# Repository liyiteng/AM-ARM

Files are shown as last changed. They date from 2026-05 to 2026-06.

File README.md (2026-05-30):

# AM-ARM200

 

AM-ARM200 is a low-cost, open-source 6+1 DoF robotic arm with a 1 kg payload, fully 3D-printable and built for embodied AI research.

Built on the open-source philosophy of SO-ARM100, it brings the platform into a new capability class while remaining easy to reproduce and affordable.

~$240 follower / ~$140 leader / ~$380 full teleoperation kit.

> Looking for the complete AlohaMini robot? See the [AlohaMini repository](https://github.com/liyiteng/alohamini).

## Updates

- **[2026-05-29]** URDF files coming soon

### What Makes It Different

- **6+1 DoF, 1 kg payload, 52 cm reach** — a capability class rarely seen at this price point
- **LeRobot & AlohaMini compatible** — works out of the box with the most popular open-source robot learning stack
- **Fully 3D-printable** — print and assemble at home in ~60 minutes
- **Open source** — CAD, firmware, and software included
- **Low cost** — ~$240 follower / ~$140 leader / ~$380 full teleoperation kit

## Gallery

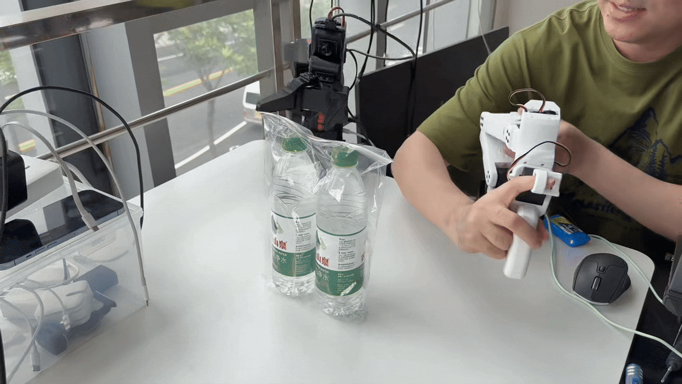
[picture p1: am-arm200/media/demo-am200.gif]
AM-ARM200


## Bill of Materials

### AM-ARM200 Follower

| Item | Qty | Unit (USD) | Subtotal (USD) |
|---|---:|---:|---:|
| Feetech STS3215 servo (12V, 1/345) | 4 | $16 | $64 |
| Feetech STS3095 servo (12V, 1/399) | 3 | $50 | $150 |
| Waveshare bus servo controller | 1 | $5 | $5 |
| 12V 4A power supply | 1 | $14 | $14 |
| Bearings, fasteners, cables | — | — | ~$10 |
| 3D-printed parts | — | — | self-print |
| **Total** | | | **~$243** |

### AM-ARM200 Leader

| Item | Qty | Unit (USD) | Subtotal (USD) |
|---|---:|---:|---:|
| Feetech STS3215 servo (5V, 1/147) | 7 | $16 | $112 |
| Waveshare bus servo controller | 1 | $5 | $5 |
| 5V 4A power supply | 1 | $10 | $10 |
| Bearings, fasteners, cables | — | — | ~$10 |
| 3D-printed parts | — | — | self-print |
| **Total** | | | **~$137** |

## Getting Started

### 1. Buy components

Order servos, controller, power supply, and small parts. See [BOM](am-arm200/bom.md).

### 2. Print parts

~20 hours on a standard FDM printer. See [3D printing guide](am-arm200/3d-print.md).

### 3. Assemble

Build a leader + follower pair in ~60 minutes. See [assembly guide](am-arm200/hardware_assembly.md).

### 4. Software setup

All software steps are in the **[lerobot_alohamini](https://github.com/liyiteng/lerobot_alohamini)** shared software repository. Follow the steps below in order — each links directly to the relevant section.

| Step | What | Where |
|---|---|---|
| 1 | Install environment | [install.md](https://github.com/liyiteng/lerobot_alohamini/blob/main/docs/alohamini/install.md) |
| 2 | Find arm ports | [§1 Port Configuration](https://github.com/liyiteng/lerobot_alohamini/blob/main/docs/alohamini/am-arm200.md#1-port-configuration) |
| 3 | Calibrate arms & teleoperate | [§3 Calibration](https://github.com/liyiteng/lerobot_alohamini/blob/main/docs/alohamini/am-arm200.md#3-calibration) |
| 4 | Record a dataset | [§5 Dataset Recording](https://github.com/liyiteng/lerobot_alohamini/blob/main/docs/alohamini/am-arm200.md#5-dataset-recording) |
| 5 | Train a policy | [§8 Training](https://github.com/liyiteng/lerobot_alohamini/blob/main/docs/alohamini/am-arm200.md#8-training) |
| 6 | Evaluate the policy | [§9 Evaluation](https://github.com/liyiteng/lerobot_alohamini/blob/main/docs/alohamini/am-arm200.md#9-evaluation) |

<details>
<summary><strong>Advanced: patch upstream LeRobot instead of using lerobot_alohamini</strong></summary>

If you already have a working LeRobot environment and prefer to stay on the upstream repo, you can add STS3095 support manually with two changes.

**Step 1 — Register STS3095 in the motor table**

In `lerobot/src/lerobot/motors/feetech/tables.py`, add `"sts3095"` to each of the five model dictionaries. STS3095 is STS-series (same protocol as STS3215), so the values mirror that motor:

```python
MODEL_CONTROL_TABLE = {
    ...
    "sts3095": STS_SMS_SERIES_CONTROL_TABLE,   # add this
}

MODEL_RESOLUTION = {
    ...
    "sts3095": 4096,                            # add this
}

MODEL_BAUDRATE_TABLE = {
    ...
    "sts3095": STS_SMS_SERIES_BAUDRATE_TABLE,   # add this
}

MODEL_ENCODING_TABLE = {
    ...
    "sts3095": STS_SMS_SERIES_ENCODINGS_TABLE,  # add this
}

MODEL_PROTOCOL = {
    ...
    "sts3095": 0,                               # add this (STS series = protocol 0)
}
```

**Step 2 — Update the follower robot definition**

In `lerobot/src/lerobot/robots/so_follower/so_follower.py`, replace the motor list with the AM-ARM200's 7-motor layout (adds `wrist_yaw` and swaps the three high-torque joints to `sts3095`):

```python
motors=(
    ("shoulder_pan",  1, "sts3095", None),
    ("shoulder_lift", 2, "sts3095", None),
    ("elbow_flex",    3, "sts3095", None),
    ("wrist_flex",    4, "sts3215", None),
    ("wrist_yaw",     5, "sts3215", None),
    ("wrist_roll",    6, "sts3215", None),
    ("gripper",       7, "sts3215", MotorNormMode.RANGE_0_100),
),
```

After these two edits, the rest of the LeRobot workflow (calibration, teleop, recording, training) is identical to the standard SO-ARM100 setup.

> Note: `lerobot_alohamini` already includes both changes — use the upstream path only if you have a specific reason to avoid the fork.

</details>

## Product Line

| Model | Build | Servos | Target Users | Buy (CN) |
|---|---|---|---|---|
| **AM-ARM200** | Fully 3D-printed | STS3215 | Makers, students, research labs | [Taobao](https://item.taobao.com/item.htm?abbucket=4&id=1015799132286) |
| **AM-ARM200 Pro** | Fully 3D-printed | Industrial STS3250 | Research institutions, university labs needing higher durability | [Taobao](https://item.taobao.com/item.htm?abbucket=4&id=1015799132286) |

> Same software stack across both versions. AM-ARM200 remains fully open-source and self-buildable. See [am-arm200-pro/](am-arm200-pro/) for Pro details.

## Team & Contact

AM-ARM200 is created by **Li Yiteng** and **Wu Zhiyong**.

- Email: liyiteng+github@gmail.com
- WeChat: liyiteng
- Videos & tutorials: Bilibili / YouTube

## Acknowledgements

- [LeRobot](https://github.com/huggingface/lerobot) — the software stack this arm targets
- [ALOHA](https://tonyzhaozh.github.io/aloha/) — the bimanual teleoperation paradigm
- [SO-ARM100](https://github.com/TheRobotStudio/SO-ARM100) — pioneered the low-cost open arm design pattern

---

If this project is useful to you, a ⭐ helps others find it.

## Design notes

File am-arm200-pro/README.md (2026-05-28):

# AM-ARM200 Pro

> **Coming Soon**

AM-ARM200 Pro is currently in development.

Key upgrade: servos upgraded from STS3215 to industrial-grade STS3250 for higher torque and reliability. Designed for research institutions and university laboratories that demand greater durability and performance. More details to follow.

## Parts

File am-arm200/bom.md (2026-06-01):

# AM-ARM200 Bill of Materials

AM-ARM200 builds on the SO-ARM100 design philosophy with increased payload capacity, longer reach, and an additional degree of freedom.

Existing SO100/SO101 users can smoothly upgrade to AM-ARM200 by simply adding the missing parts.

## Follower Arm

| Item | Model / Notes | Qty | Unit Cost (US/EU) | Buy (US) | Unit Cost (CN) | Buy (CN) |
|---|---|----:|---|---|---|---|
| Servo motor | Feetech STS3215 (12V 1/345) | 4 | $15.97 | [Alibaba](https://www.alibaba.com/product-detail/Lerobot-360-Degree-Smart-Servo-for_1601563310522.html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) | ¥110 | [Taobao](https://e.tb.cn/h.64H9u3maGWzIp5Q?tk=T5liexkG6Yz) |
| Servo motor | Feetech STS3095 (12V 1/345) | 3 | $50.37 | [Alibaba](https://www.alibaba.com/product-detail/FEETECH-STS3095-12V-95KG-servo-AI_1601045980686.html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) | ¥345 | [Taobao](https://item.taobao.com/item.htm?id=766143777848&skuId=6096958421597) |
| Hex socket screw | M3×10 | 74 | — | — | ¥6 | [Taobao](https://e.tb.cn/h.R0nMFj8y9riNyJl?tk=HNii5rHz4NJ) |
| Heat-set insert | M3×5×4 | 4 | — | Amazon | ¥5 | [Taobao](https://item.taobao.com/item.htm?id=809241671998) |
| Servo extension cable | SCS 3-pin, 26 cm | 6 | $0.43 | [AliExpress](https://www.aliexpress.com/item/1005008074862037.html) | ¥3 | [Taobao](https://item.taobao.com/item.htm?id=616460581906) |
| Power supply | DC 12V 4A 48W AC Adapter | 1 | $13.76 | [Amazon](https://www.amazon.com/Snsnlent-Adapter-5-5x2-1mm-Monitor-Voltage/dp/B085ZXPD34/) | ¥24 | [Taobao](https://item.taobao.com/item.htm?id=544862301228) |
| USB Type-C cable | — | 1 | $7.00 | [Amazon](https://www.amazon.com/Charging-etguuds-Charger-Braided-Compatible/dp/B0B8NWLLW2/) | ¥20 | [Tmall](https://detail.tmall.com/item.htm?id=754024805047) |
| Waveshare Bus Servo Controller | — | 1 | $5.00 | [Waveshare](https://www.waveshare.com/bus-servo-adapter-a.htm) | ¥27 | [Tmall](https://detail.tmall.com/item.htm?id=738817173460) |
| 3D-printed parts | PLA/PETG/ABS — [STL](stl/) / [STP](stp/) | 1 | — | — | — | — |

**Follower Total: $243.33**

---

## Leader Arm

| Item | Model / Notes | Qty | Unit Cost (US) | Buy (US) | Unit Cost (CN) | Buy (CN) |
|---|---|----:|---|---|---|---|
| Servo motor | Feetech STS3215 (5V 1/147) | 7 | $15.97 | [Alibaba](https://www.alibaba.com/product-detail/Lerobot-360-Degree-Smart-Servo-for_1601563310522.html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) | ¥110 | [Taobao](https://e.tb.cn/h.64H9u3maGWzIp5Q?tk=T5liexkG6Yz) |
| Heat-set insert | M3×5×4, total 36 pcs (Servo Mount×24, Side Panel×12) | 4 | — | Amazon | ¥5 | [Taobao](https://item.taobao.com/item.htm?id=809241671998) |
| Power supply | DC 5V AC Adapter | 1 | $12.99 | [Amazon](https://www.amazon.com/Facmogu-Switching-Transformer-Compatible-5-5x2-1mm/dp/B087LY41PV/) | — | — |
| USB Type-C cable | — | 1 | $7.19 | [Amazon](https://www.amazon.com/Charging-etguuds-Charger-Braided-Compatible/dp/B0B8NWLLW2/) | ¥20 | [Tmall](https://detail.tmall.com/item.htm?id=754024805047) |
| Waveshare Bus Servo Controller | — | 1 | $12.47 | [Amazon](https://www.amazon.com/Waveshare-Integrates-Control-Circuit-Supports/dp/B0CTMM4LWK/) | ¥27 | [Tmall](https://detail.tmall.com/item.htm?id=738817173460) |
| 3D-printed parts | PLA/PETG/ABS — [STL](stl/) / [STP](stp/) | 1 | — | — | — | — |

**Leader Total: $144.44**

---

## Optional

| Item | Model / Notes | Qty | Unit Cost (US) | Buy (US) | Unit Cost (CN) | Buy (CN) |
|---|---|----:|---|---|---|---|
| USB camera | 720p, 36×36 mm form factor | 1 | — | Amazon | ¥125 | [Taobao](https://item.taobao.com/item.htm?id=666278411821) |
| M2×12 Phillips screw | For camera mounts | 2 | — | — | — | — |
| Bearing | 12×18×4 mm (ID × OD × W) | 2 | $0.30 | [Amazon](https://www.amazon.com/XIKE-6701-2RS-Bearings-12x18x4mm-Pre-Lubricated/dp/B09D2RQ4Y1) | ¥6 | [Tmall](https://detail.tmall.com/item.htm?id=824704356695) |

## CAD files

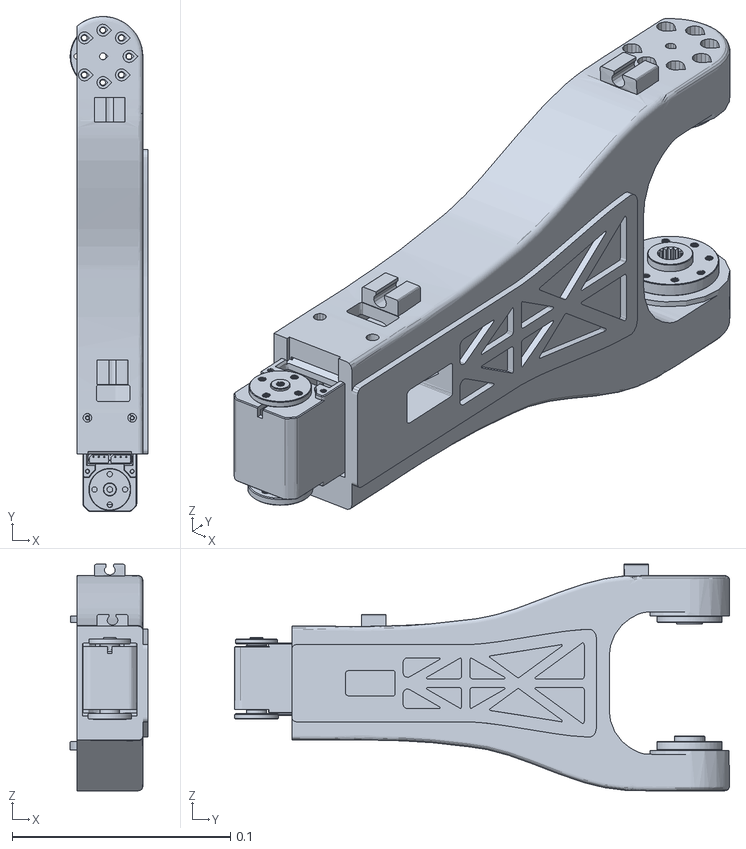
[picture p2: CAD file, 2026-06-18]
am-arm200-pro/urdf/am-arm200pro-meshes/left_Lower_Arm.STL
0.0356 x 0.227 x 0.104

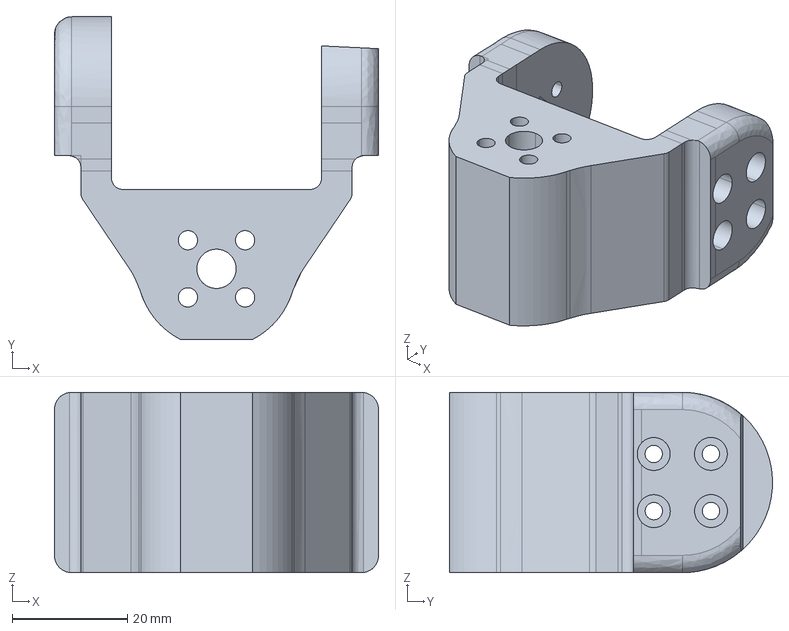
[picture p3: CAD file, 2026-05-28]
am-arm200/stp/follower/OB_F_J5_Elbow_Wrist_Bracket.stp
56.1 x 55.9 x 31.2 mm

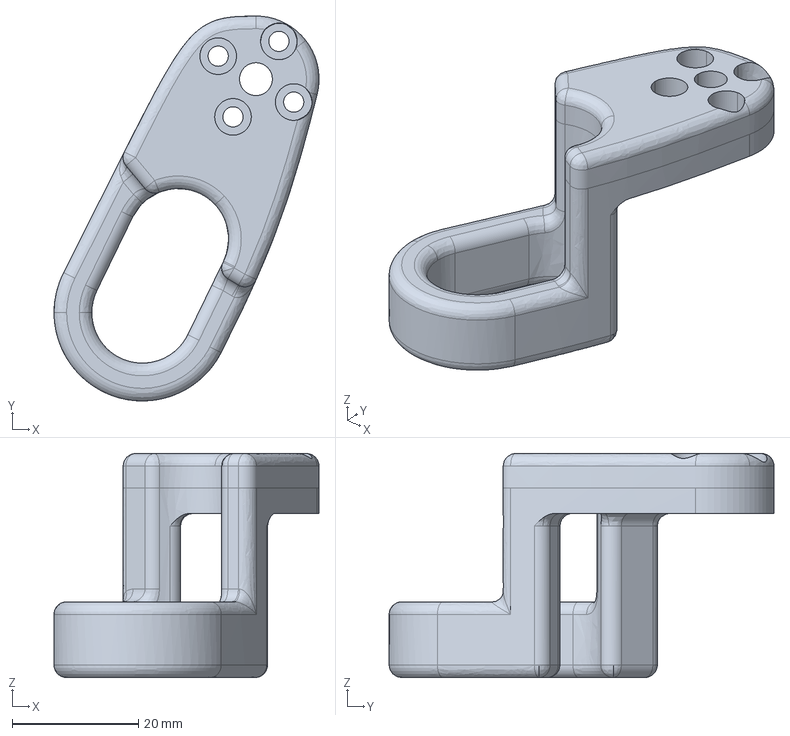
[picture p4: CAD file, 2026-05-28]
am-arm200/stp/leader/O_L_J7_Trigger.stp
42.0 x 61.0 x 35.5 mm

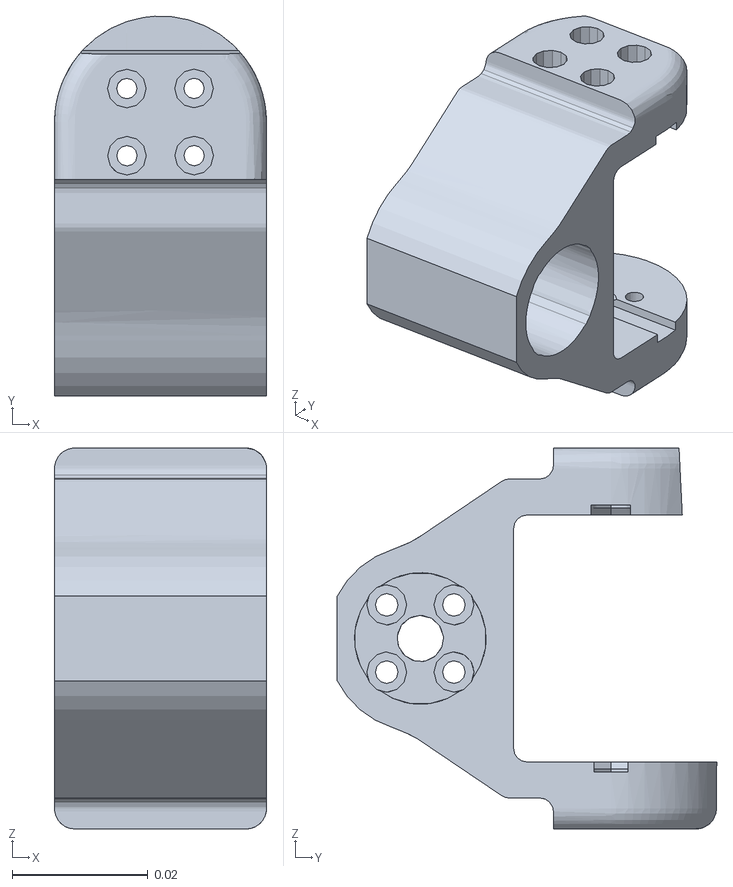
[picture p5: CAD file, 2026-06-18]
am-arm200/urdf/am-arm200-meshes/left_Wrist_Pitch_Roll.STL
0.0312 x 0.0559 x 0.0561

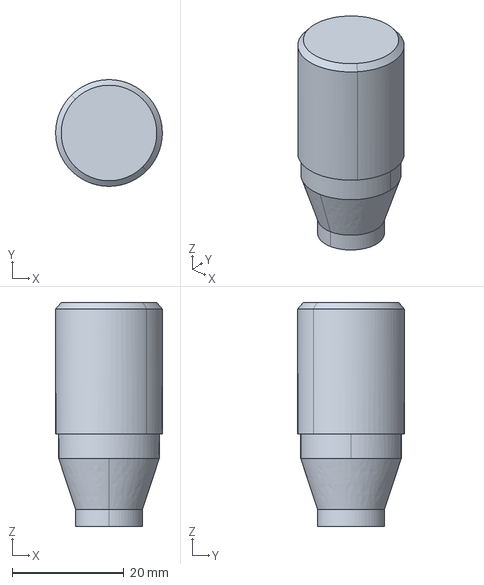
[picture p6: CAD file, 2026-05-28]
am-arm200/stp/follower/OB_F_J5_Pin_Bearing.stp
19.1 x 19.1 x 40.1 mm

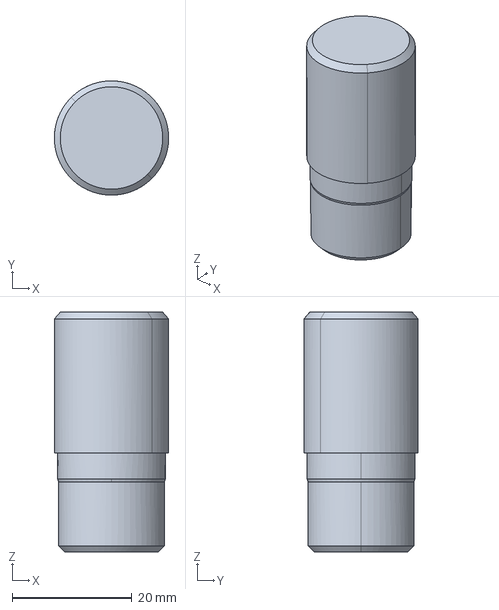
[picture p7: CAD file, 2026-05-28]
am-arm200/stp/leader/O_L_J5_Pin_No_Bearing.stp
19.1 x 19.1 x 40.1 mm

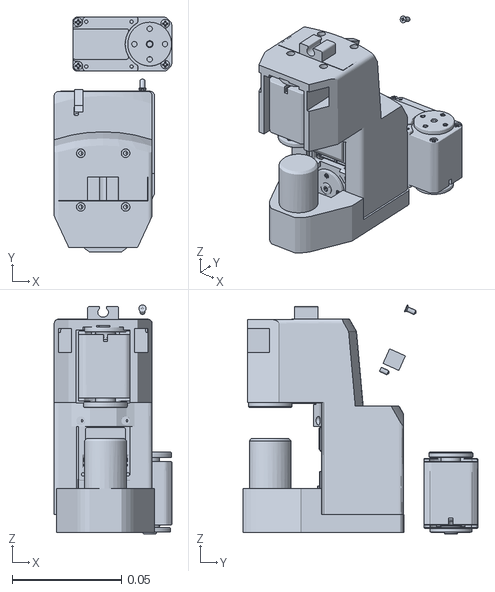
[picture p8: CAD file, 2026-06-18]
am-arm200/urdf/am-arm200-meshes/left_wrist_yaw.STL
0.0538 x 0.107 x 0.105

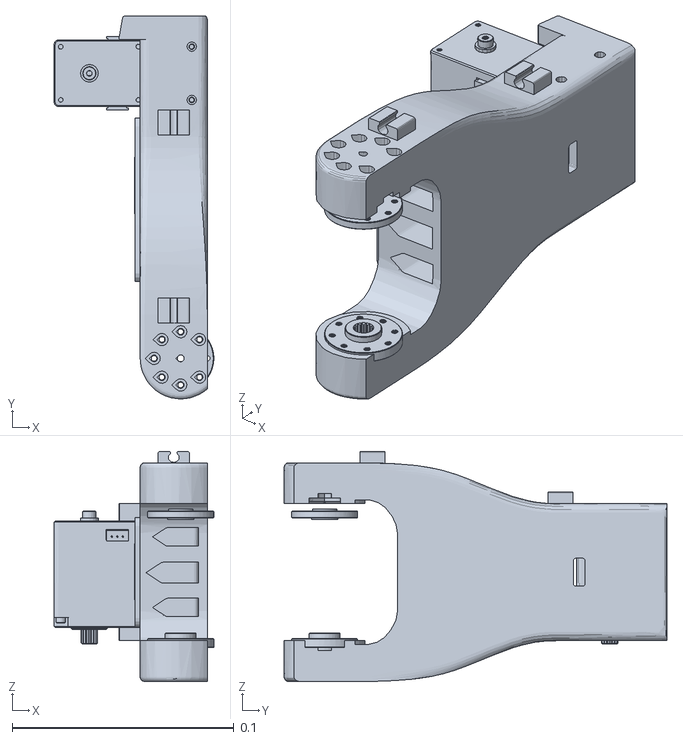
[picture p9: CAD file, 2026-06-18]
am-arm200-pro/urdf/am-arm200pro-meshes/left_Upper_Arm.STL
0.072 x 0.173 x 0.104

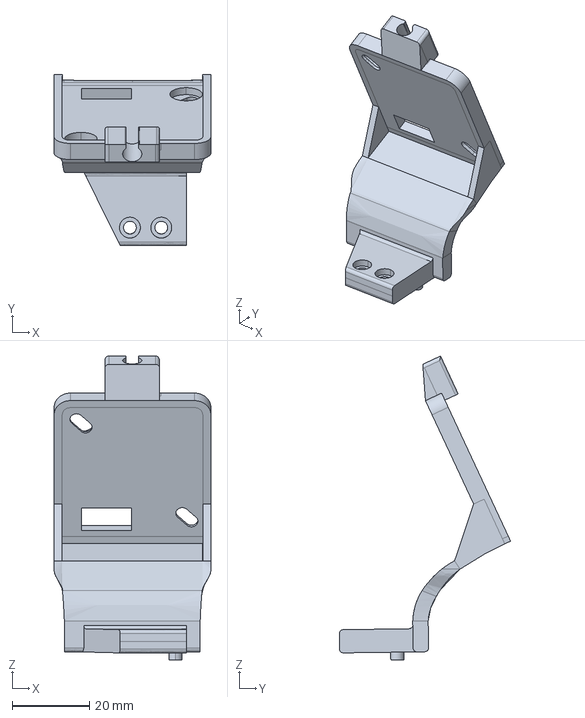
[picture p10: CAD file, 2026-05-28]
am-arm200/stp/follower/OB_F_Camera.stp
40.5 x 44.2 x 78.5 mm

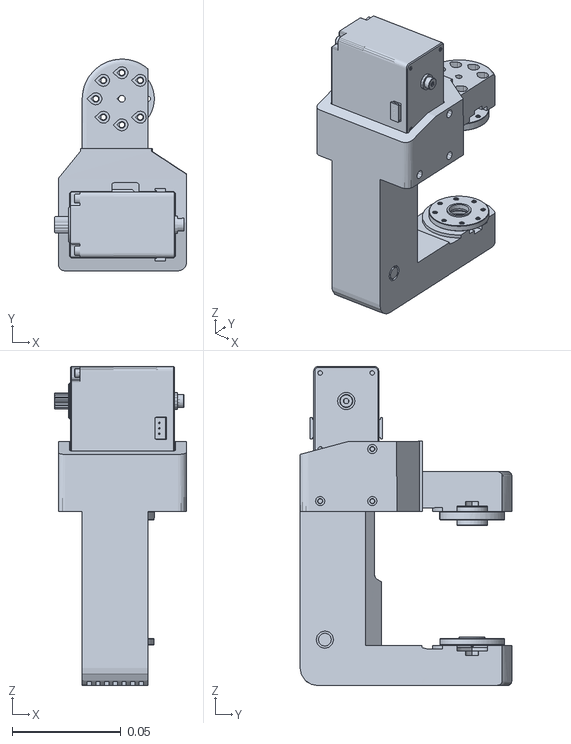
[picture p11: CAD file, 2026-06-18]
am-arm200/urdf/am-arm200-meshes/left_Rotation_Pitch.STL
0.0609 x 0.0975 x 0.147

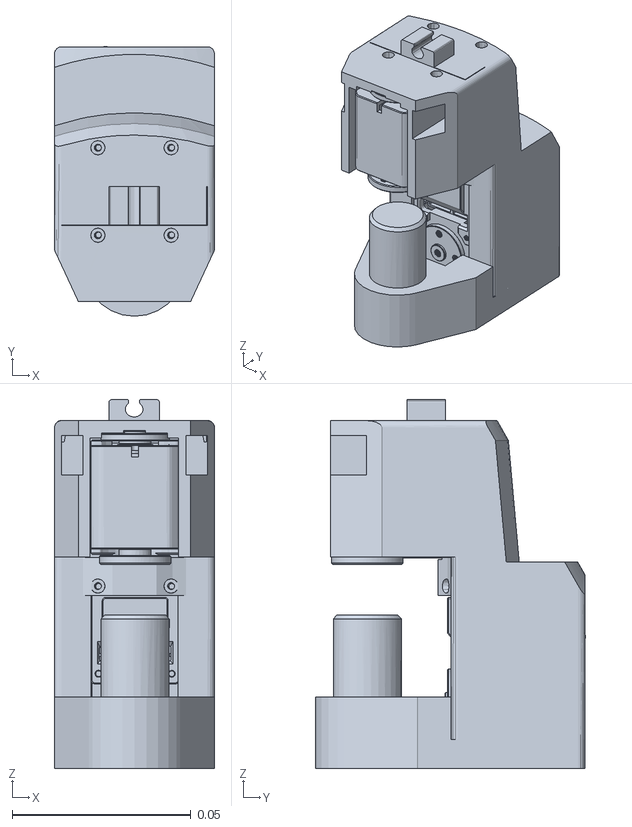
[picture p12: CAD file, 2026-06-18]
am-arm200-pro/urdf/am-arm200pro-meshes/left_wrist_yaw.STL
0.0448 x 0.0755 x 0.103

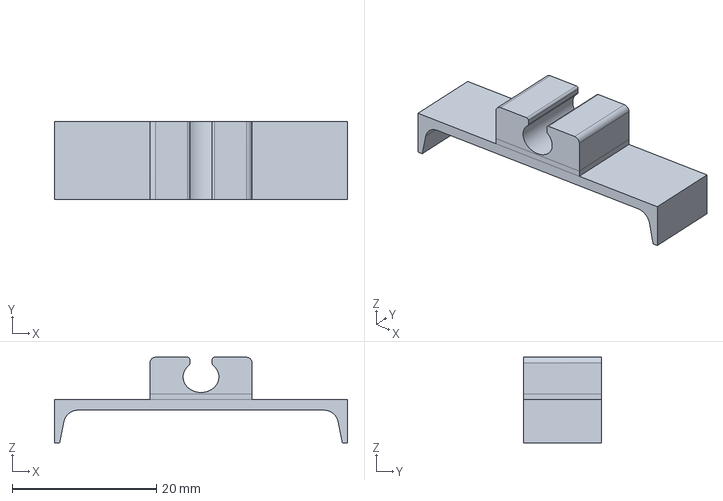
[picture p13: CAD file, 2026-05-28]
am-arm200/stp/follower/OB_F_J56_Top.stp
40.6 x 10.8 x 11.9 mm

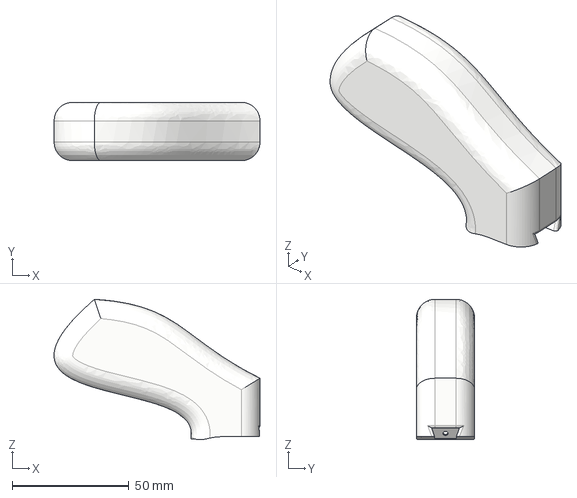
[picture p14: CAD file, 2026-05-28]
am-arm200/stp/leader/O_L_J7_Handle.stp
88.1 x 25.0 x 60.1 mm

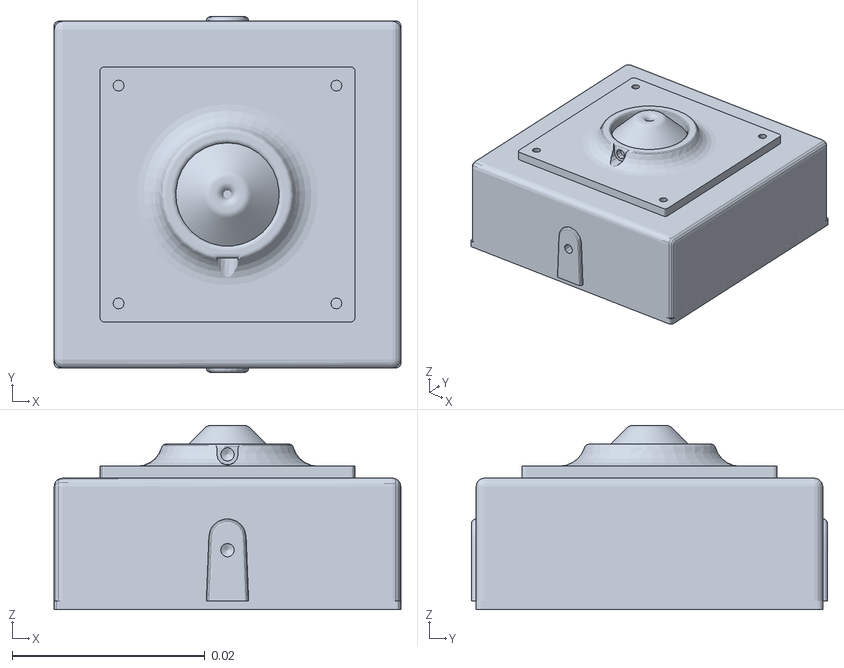
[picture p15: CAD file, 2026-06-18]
am-arm200/urdf/am-arm200-meshes/left_camera.STL
0.036 x 0.037 x 0.0191

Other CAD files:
am-arm200-pro/urdf/am-arm200pro-meshes/left_Wrist_Pitch_Roll.STL
am-arm200-pro/urdf/am-arm200pro-meshes/left_Rotation_Pitch.STL
am-arm200/stp/follower/OB_F_J3_Shoulder.stp
am-arm200-pro/urdf/am-arm200pro-meshes/left_Base.STL
am-arm200-pro/urdf/am-arm200pro-meshes/left_Fixed_Jaw.STL
am-arm200-pro/urdf/am-arm200pro-meshes/left_Moving_Jaw.STL
am-arm200-pro/urdf/am-arm200pro-meshes/left_camera.STL
am-arm200/stl/follower/OB_F_Camera.stl
am-arm200/stl/follower/OB_F_J3_Shoulder.stl
am-arm200/stl/follower/OB_F_J4_Elbow.stl
am-arm200/stl/follower/OB_F_J56_Bottom.stl
am-arm200/stl/follower/OB_F_J56_Top.stl
am-arm200/stl/follower/OB_F_J56_Wrist_Housing.stl
am-arm200/stl/follower/OB_F_J5_Elbow_Wrist_Bracket.stl
am-arm200/stl/follower/OB_F_J5_Pin_Bearing.stl
am-arm200/stl/follower/OB_F_J5_Pin_No_Bearing.stl
am-arm200/stl/follower/OB_F_J7_Gripper.stl
am-arm200/stl/follower/OB_F_J7_Jaw.stl
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

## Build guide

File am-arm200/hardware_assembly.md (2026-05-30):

# Hardware Assembly Guide

This guide covers the AM-ARM200 follower arm assembly. Install all screws loosely at first, then tighten them after the parts are aligned.

## Servo ID Setup

Before assembly, assign the correct ID to each servo. We recommend using the [`lerobot_alohamini`](https://github.com/liyiteng/lerobot_alohamini)debug command.

### Option 1: lerobot_alohamini (Recommended)

Set the servo ID with the `lerobot_alohamini` [debug command](https://github.com/liyiteng/lerobot_alohamini/blob/main/examples/debug):
```bash
python examples/debug/motors.py configure_motor_id \
  --id 1 \
  --set_id 2 \
  --port /dev/ttyACM0
```

### Option 2: FD Debug Tool

You can also use the Feetech [FD Debug Tool](https://www.feetechrc.com/Data/feetechrc/upload/file/20240622/FD1.9.8.3.zip), for example FD Debug Tool v1.9.8.3.

1. Download and install the FD Debug Tool.
2. Connect one servo to your computer through the Waveshare Bus Servo Controller.
3. Open the FD Debug Tool.
4. Select the correct COM port and baud rate. The typical baud rate is `1000000`.
5. Click `Scan Servo` to detect the connected servo and read its current ID.
6. Enter the target ID in the ID field.
7. Click `Write` or `Save` to update the servo ID.
8. Disconnect the servo and repeat the process for the remaining servos.

## Leader Arm (5V)

### 1. Configure the servos

Connect the 5V power supply to the servo controller, connect the controller to your PC with a USB-C cable, and connect one servo to the controller.

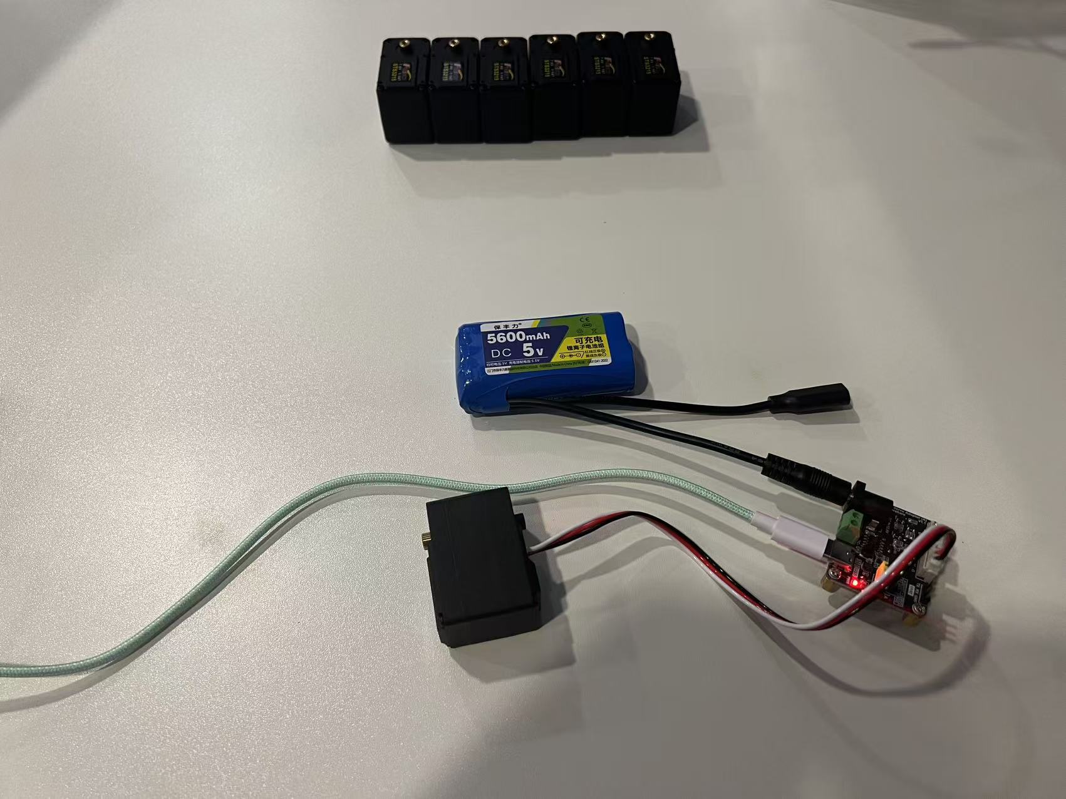
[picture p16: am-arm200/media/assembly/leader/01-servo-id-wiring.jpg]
Leader servo ID wiring


Set the servo IDs one by one.

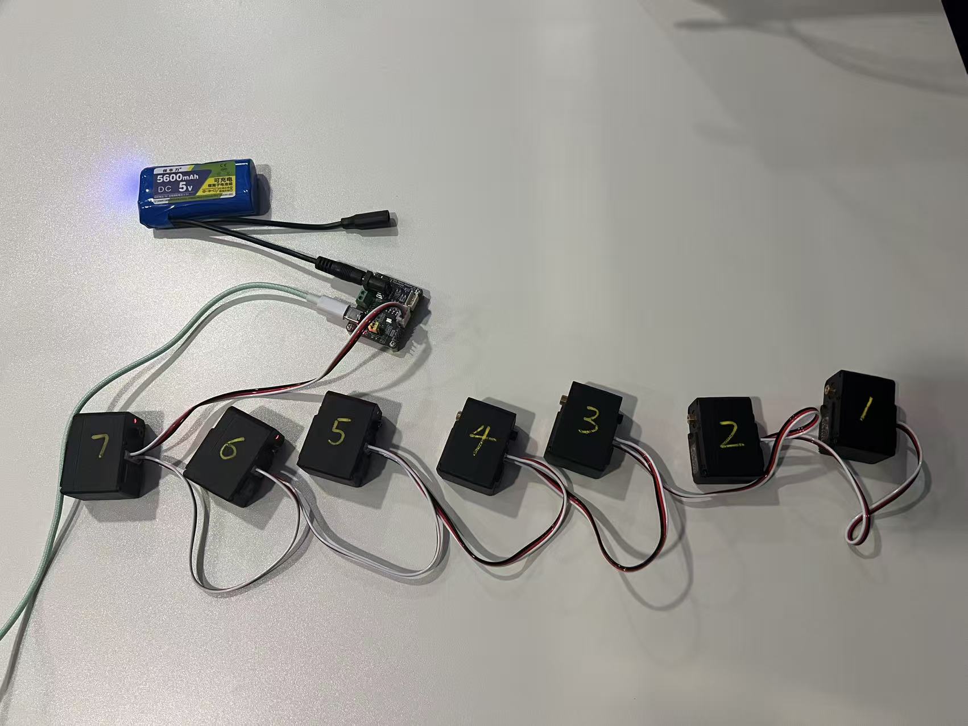
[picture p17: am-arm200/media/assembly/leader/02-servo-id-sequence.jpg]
Leader servo ID sequence


Use the following layout as the reference for servo IDs 1-7 on the leader arm.

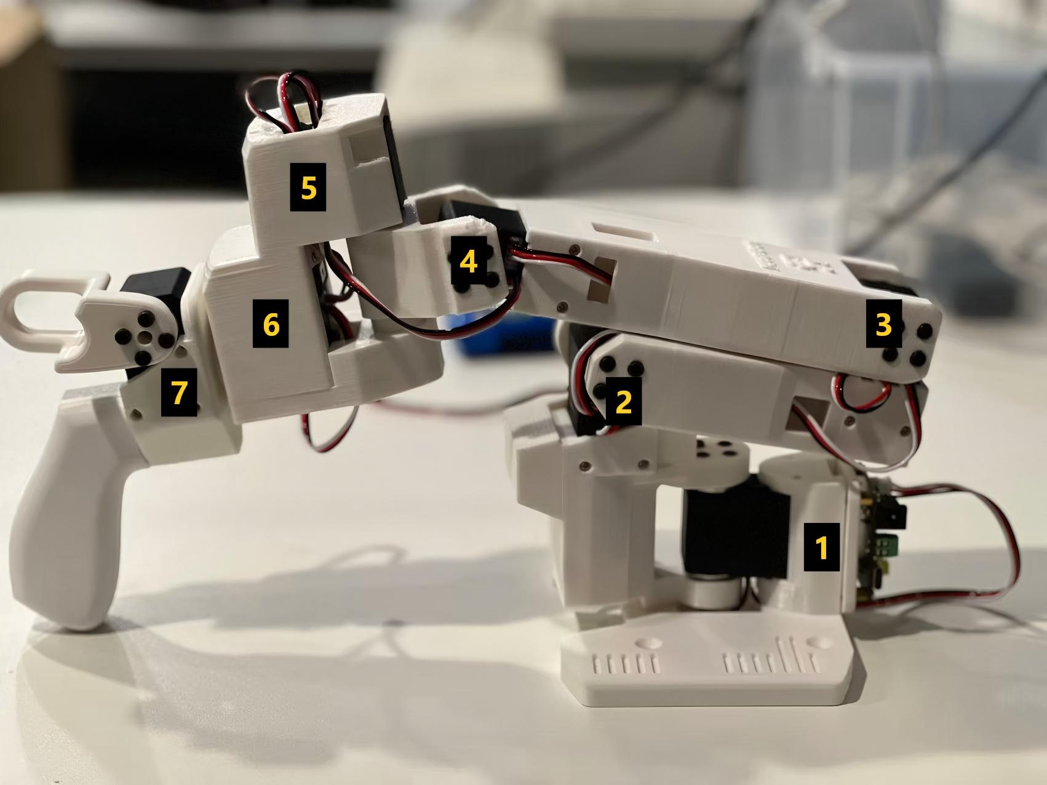
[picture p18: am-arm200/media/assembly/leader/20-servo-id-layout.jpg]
Leader servo ID layout


The 5V 1/147 servos are configured for multi-turn mode at the factory. Using the same `lerobot_alohamini` [debug command](https://github.com/liyiteng/lerobot_alohamini/blob/main/examples/debug) setup, set the servo phase to `12` to reset them to single-turn mode:

```bash
python examples/debug/motors.py configure_motor_phase \
  --set_phase 12 \
  --port /dev/ttyACM0
```

After configuration, use `get_motors_states` to check the servo status:

```bash
python examples/debug/motors.py get_motors_states \
  --port /dev/ttyACM0
```

### 2. Assemble the base and shoulder

After the servo IDs and phase are configured, start the mechanical assembly.

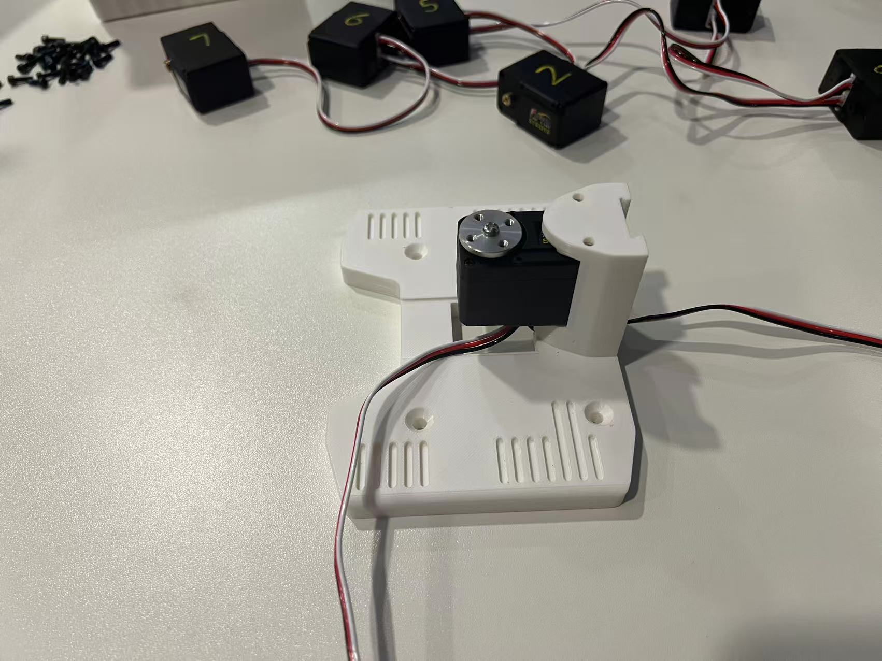
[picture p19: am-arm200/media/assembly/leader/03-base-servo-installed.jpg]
Leader base servo installed


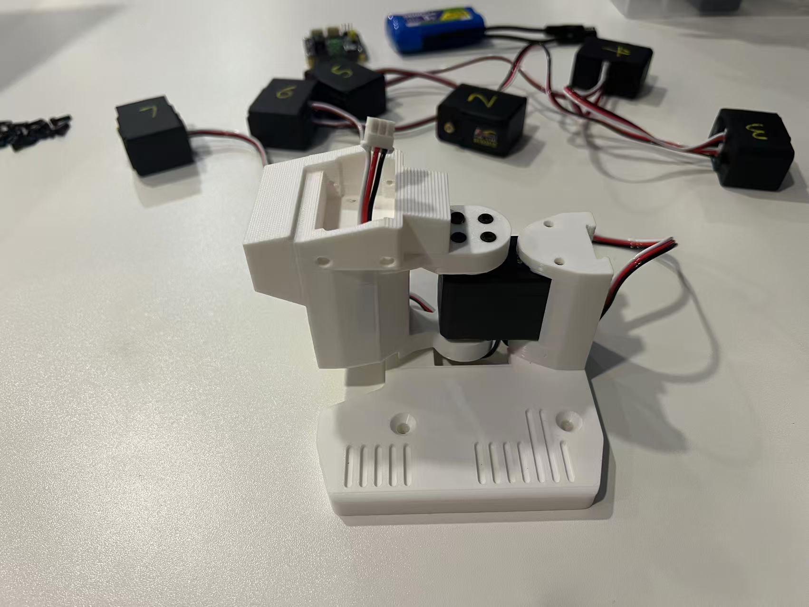
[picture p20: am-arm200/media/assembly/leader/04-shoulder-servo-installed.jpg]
Leader shoulder servo installed


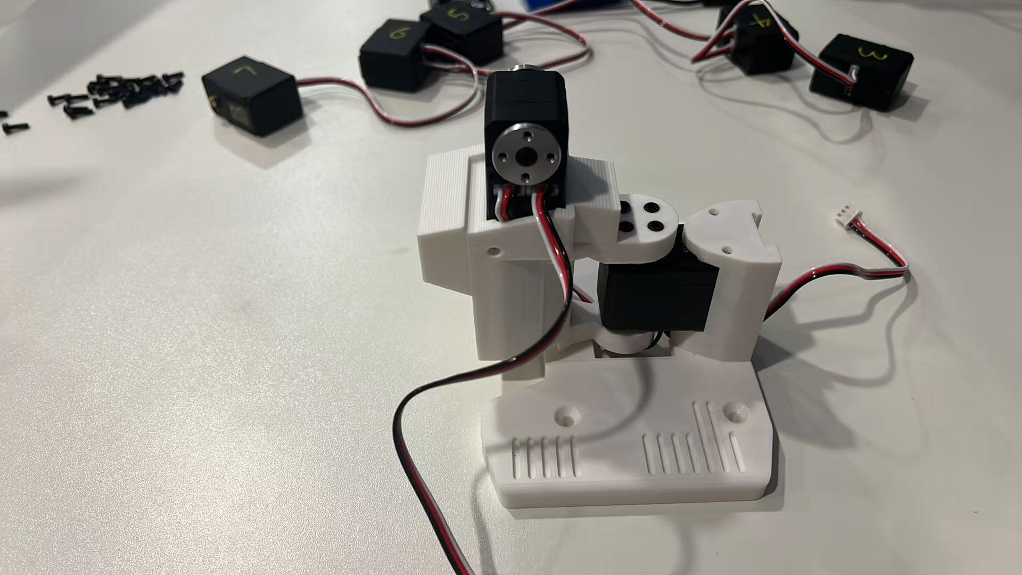
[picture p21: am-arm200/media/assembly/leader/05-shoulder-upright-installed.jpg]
Leader shoulder upright installed


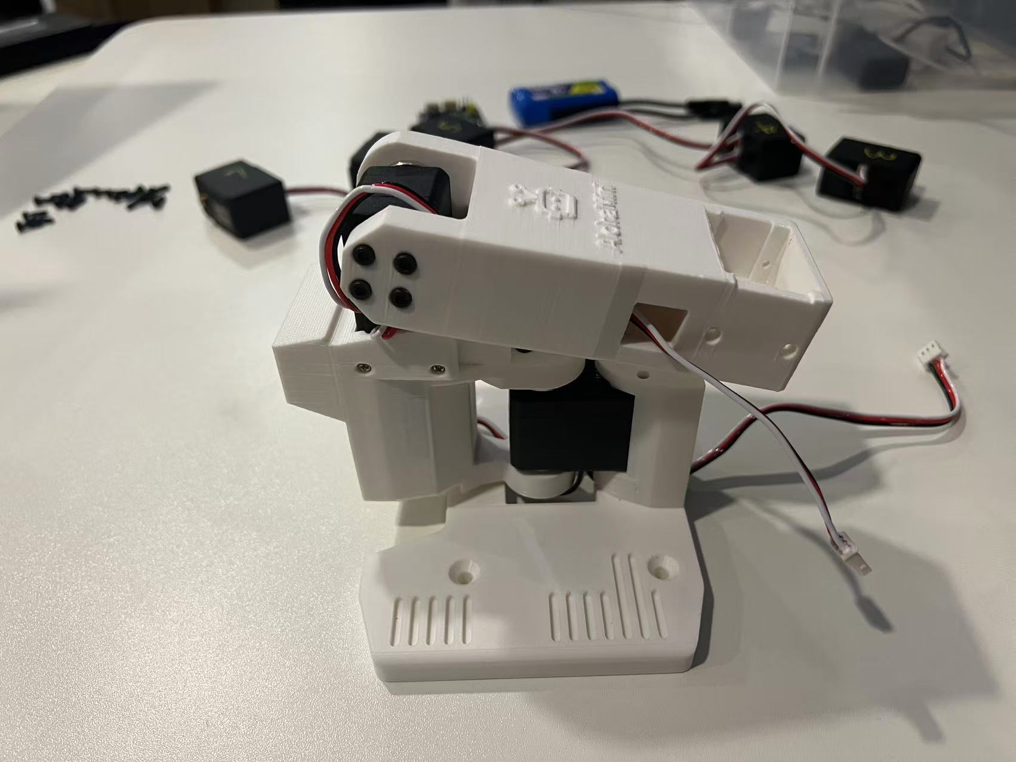
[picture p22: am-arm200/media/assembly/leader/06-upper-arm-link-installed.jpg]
Leader upper arm link installed


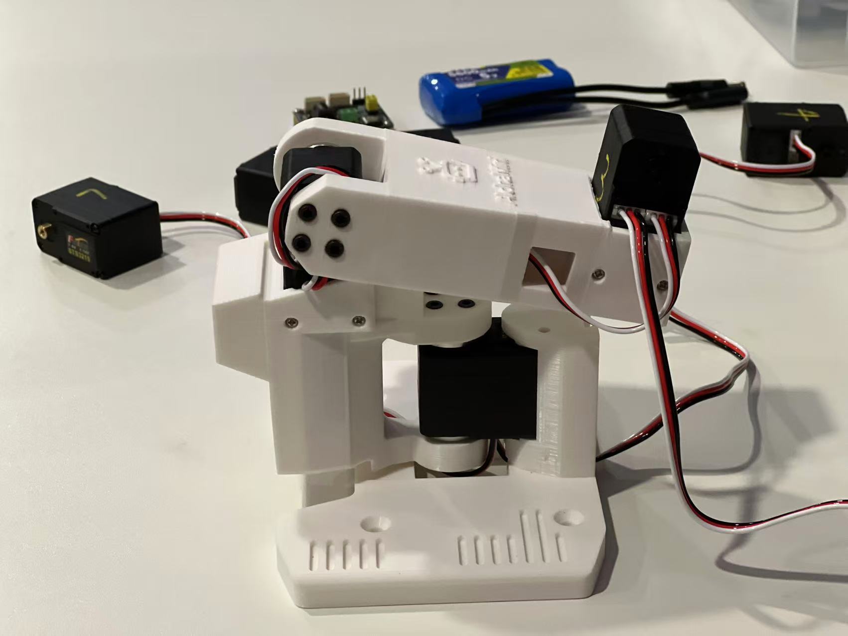
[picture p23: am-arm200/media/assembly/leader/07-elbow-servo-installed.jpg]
Leader elbow servo installed


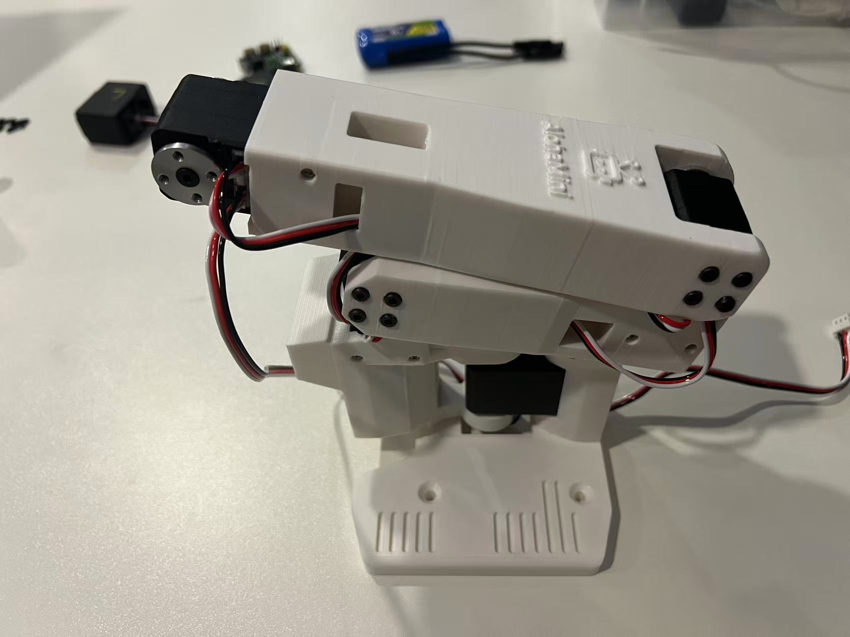
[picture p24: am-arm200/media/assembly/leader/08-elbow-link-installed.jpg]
Leader elbow link installed


### 3. Install heat-set inserts

Install the heat-set inserts into the J56 printed part.

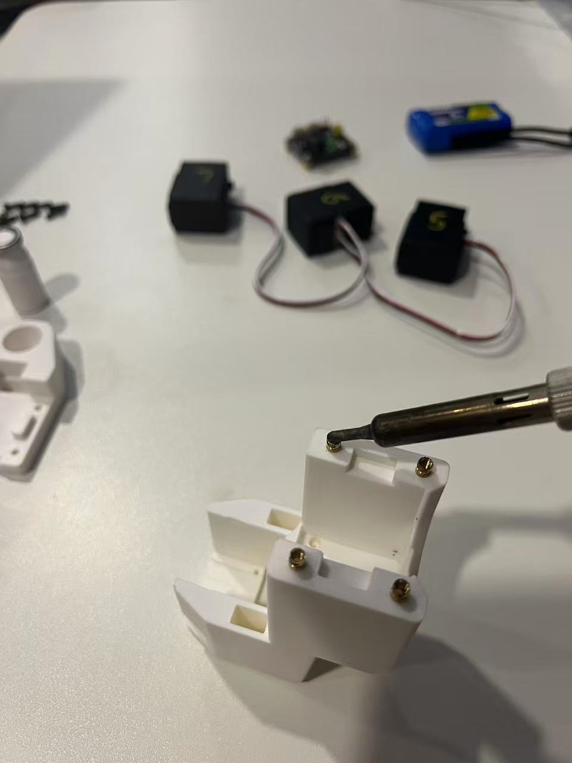
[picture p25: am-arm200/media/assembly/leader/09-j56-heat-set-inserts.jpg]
J56 heat-set inserts


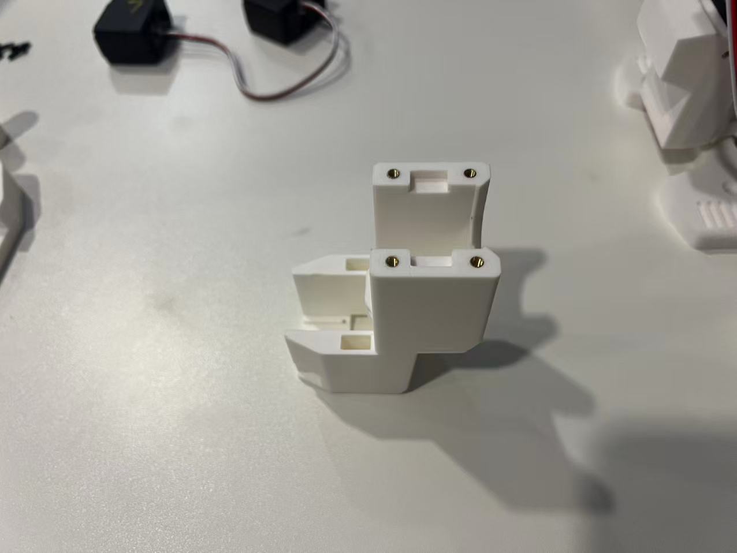
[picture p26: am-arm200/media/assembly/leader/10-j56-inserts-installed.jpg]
J56 heat-set inserts installed


### 4. Assemble the wrist

Install the wrist servo, bearing, and wrist cover.

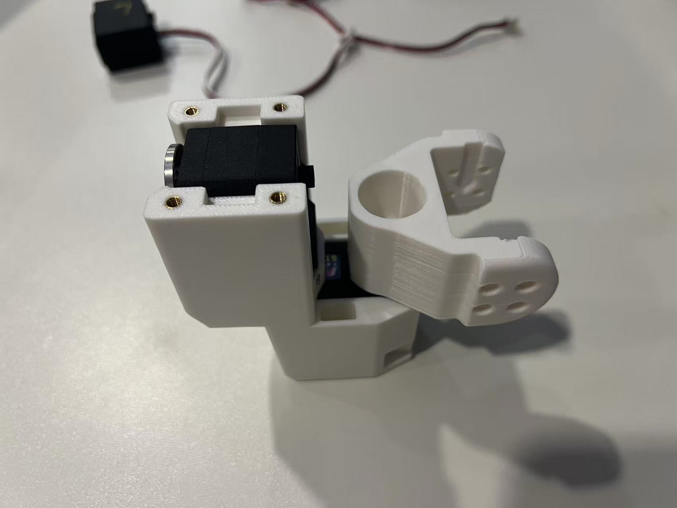
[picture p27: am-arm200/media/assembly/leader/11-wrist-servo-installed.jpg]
Leader wrist servo installed


Install the pin and bearing. Alternatively, use the no-bearing version: `O_L_J5_Pin_No_Bearing.stl`.
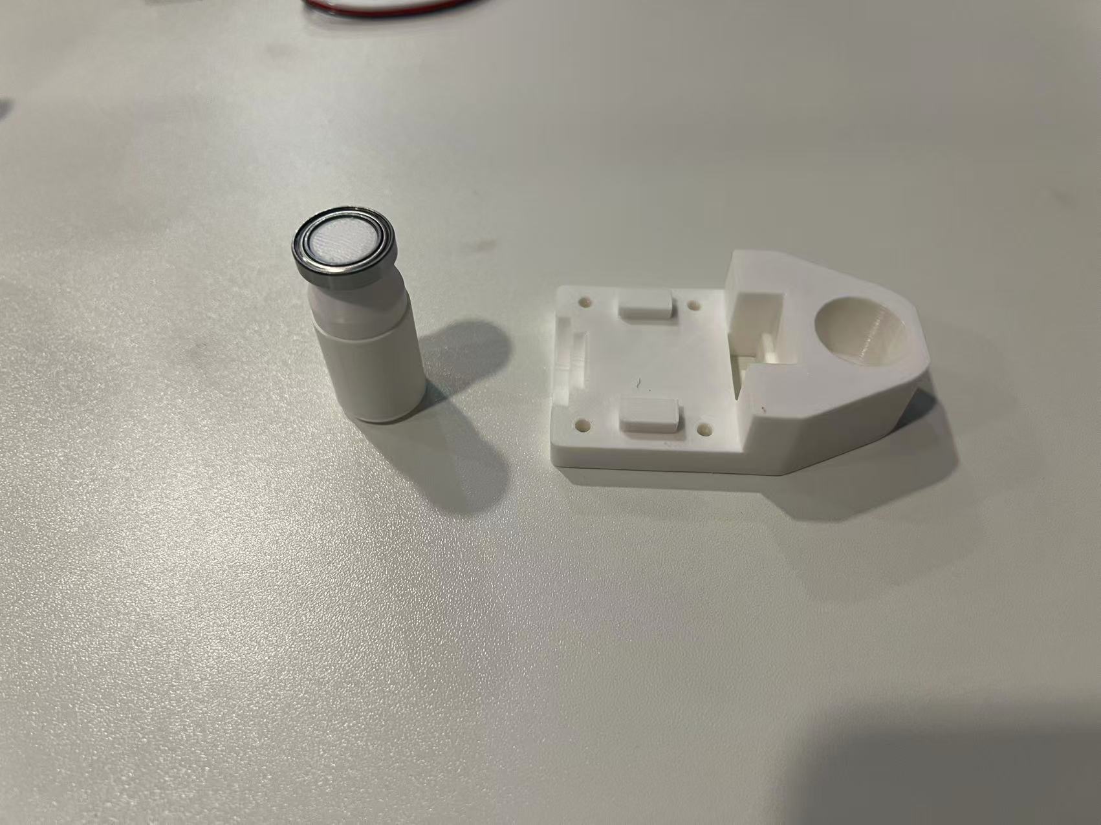
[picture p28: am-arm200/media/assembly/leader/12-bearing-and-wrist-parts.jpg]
Leader bearing and wrist parts


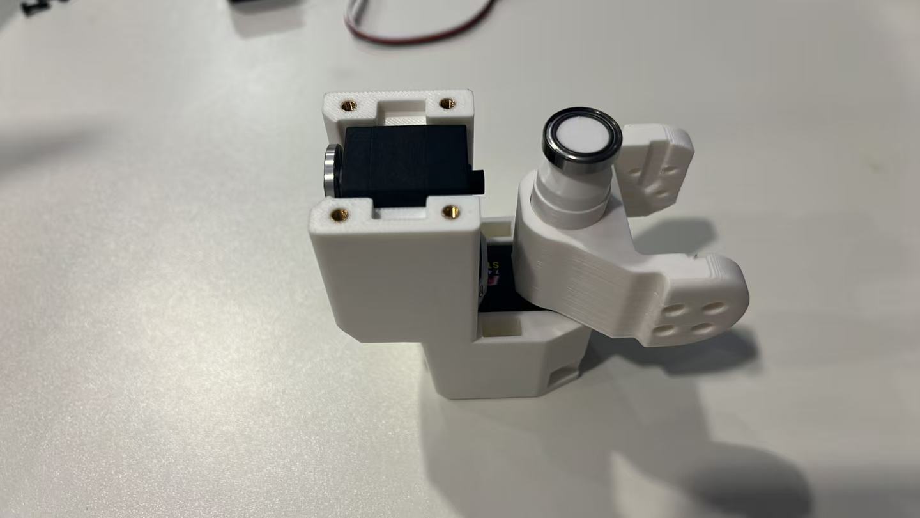
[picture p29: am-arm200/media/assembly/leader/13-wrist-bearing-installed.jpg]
Leader wrist bearing installed


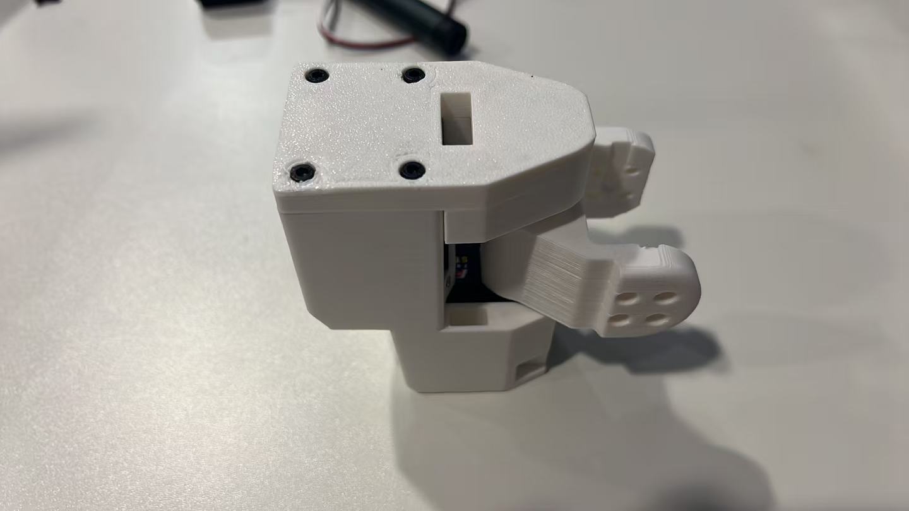
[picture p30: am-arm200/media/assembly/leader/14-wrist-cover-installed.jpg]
Leader wrist cover installed


### 5. Assemble the gripper

Install the gripper linkage and gripper servo.

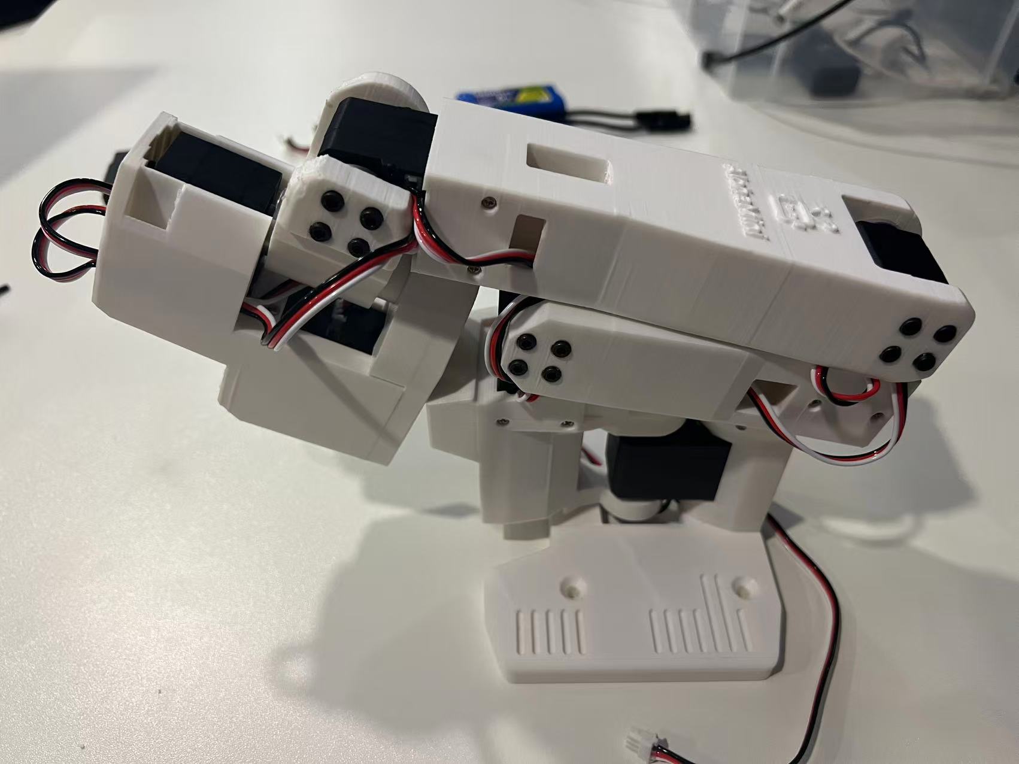
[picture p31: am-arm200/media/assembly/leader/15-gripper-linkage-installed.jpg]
Leader gripper linkage installed


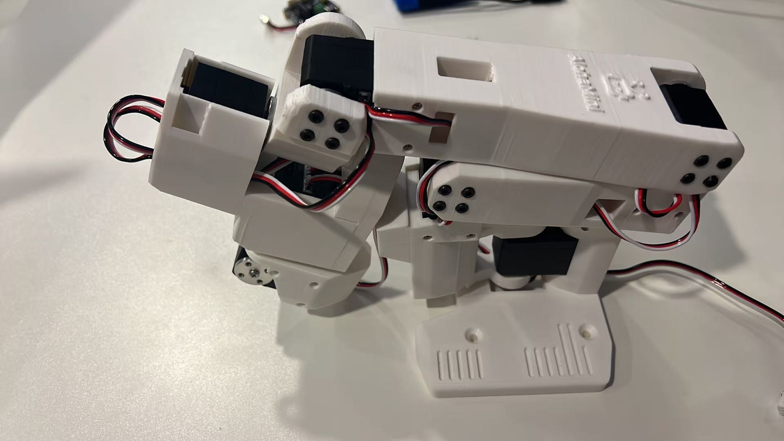
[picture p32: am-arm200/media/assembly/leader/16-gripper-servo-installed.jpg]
Leader gripper servo installed


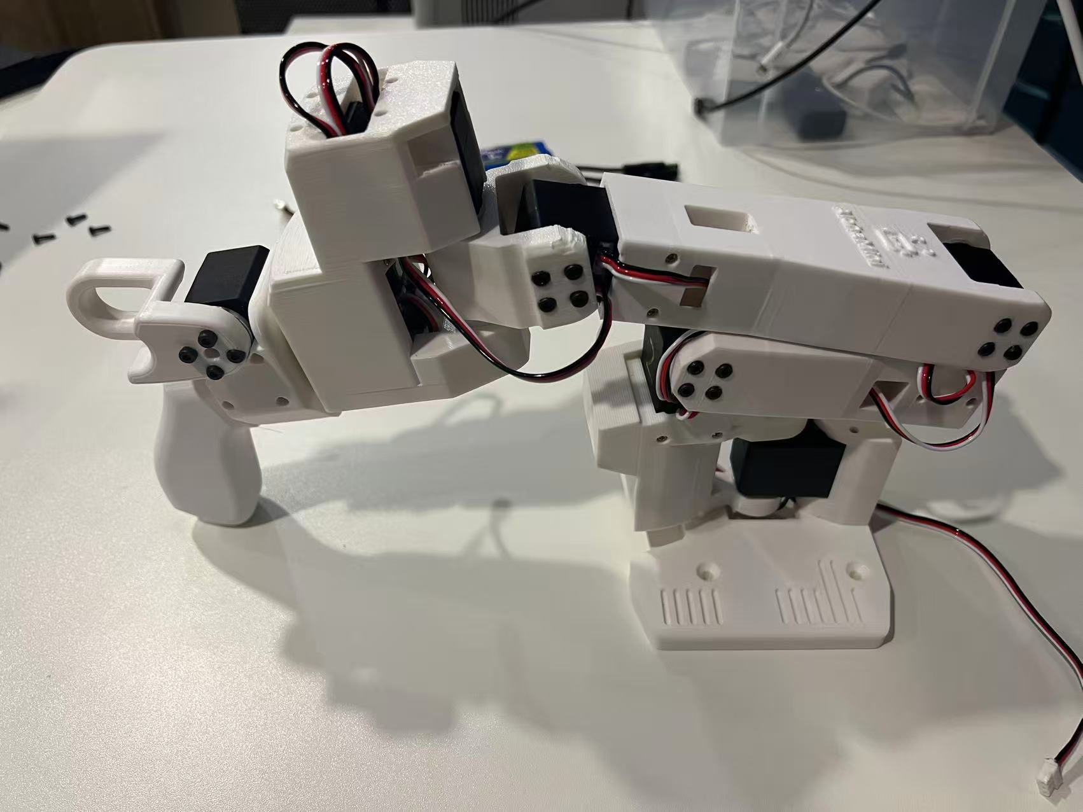
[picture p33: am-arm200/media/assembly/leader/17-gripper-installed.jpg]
Leader gripper installed


### 6. Install the servo controller

Install the servo controller on the base and check the wiring.

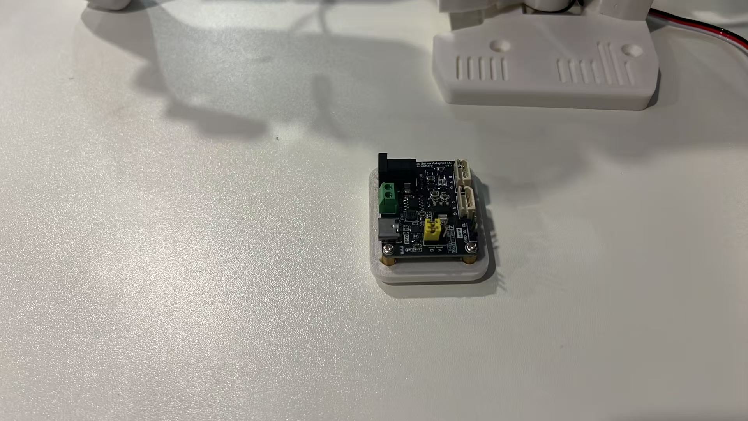
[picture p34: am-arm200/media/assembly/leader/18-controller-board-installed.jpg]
Leader controller board installed


### 7. Final check

The leader arm assembly is complete. Check that each joint moves freely and that no cables are pinched.

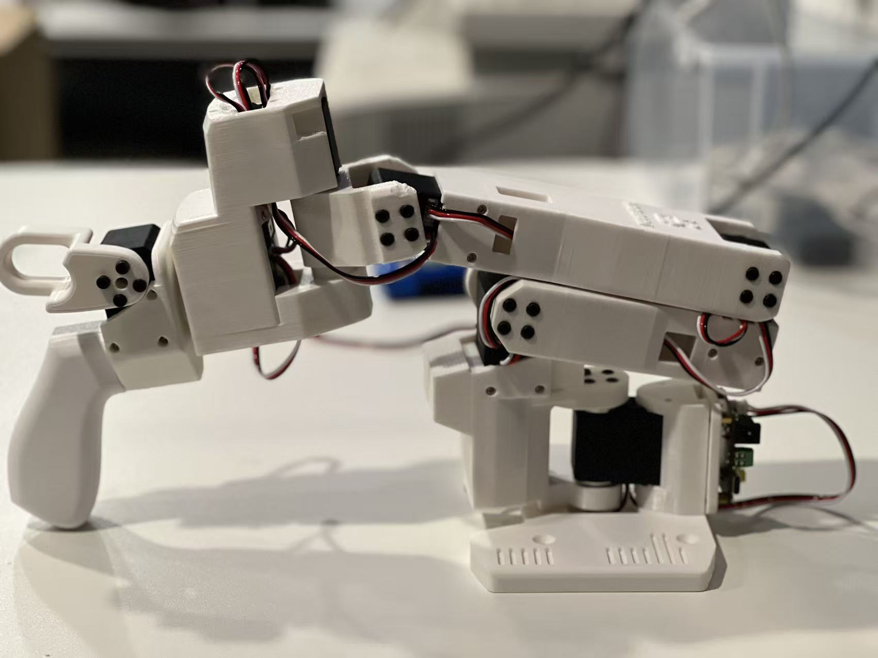
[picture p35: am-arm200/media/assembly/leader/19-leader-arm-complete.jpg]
Leader arm complete


## Follower Arm (12V)

### 1. Prepare the servos

Label the servos before assembly so each joint can be identified later during calibration. The servo ID setup process is the same as the leader arm, but the follower arm does not require phase configuration.

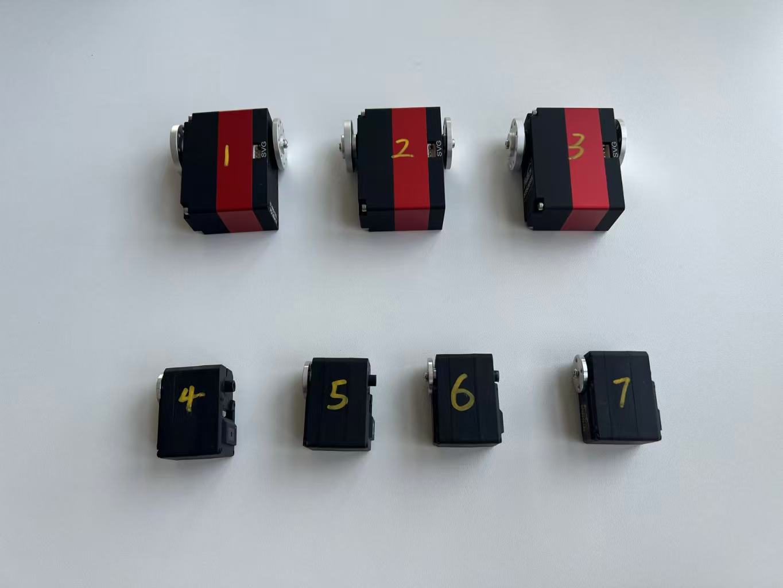
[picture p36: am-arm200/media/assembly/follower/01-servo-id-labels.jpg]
Follower servo ID labels


### 2. Assemble the base and shoulder

Install the base servo into the base printed part and route the cable through the opening.

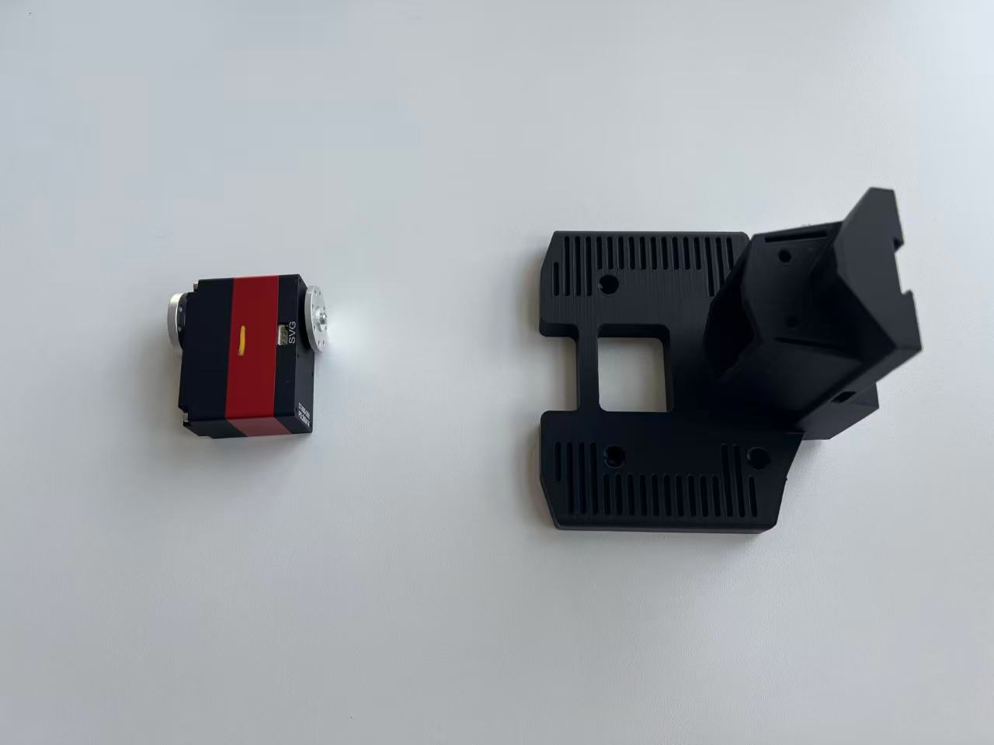
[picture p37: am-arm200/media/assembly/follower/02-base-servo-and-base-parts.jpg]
Base servo and base parts


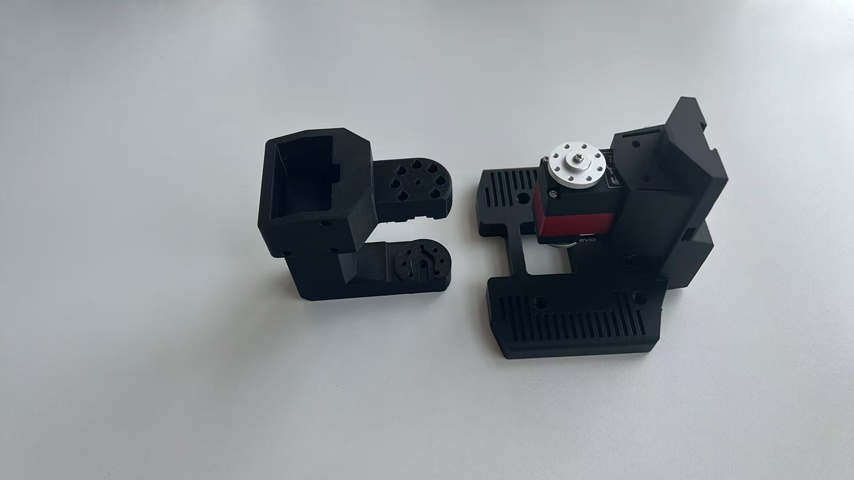
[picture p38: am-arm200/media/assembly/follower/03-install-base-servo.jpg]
Install the base servo


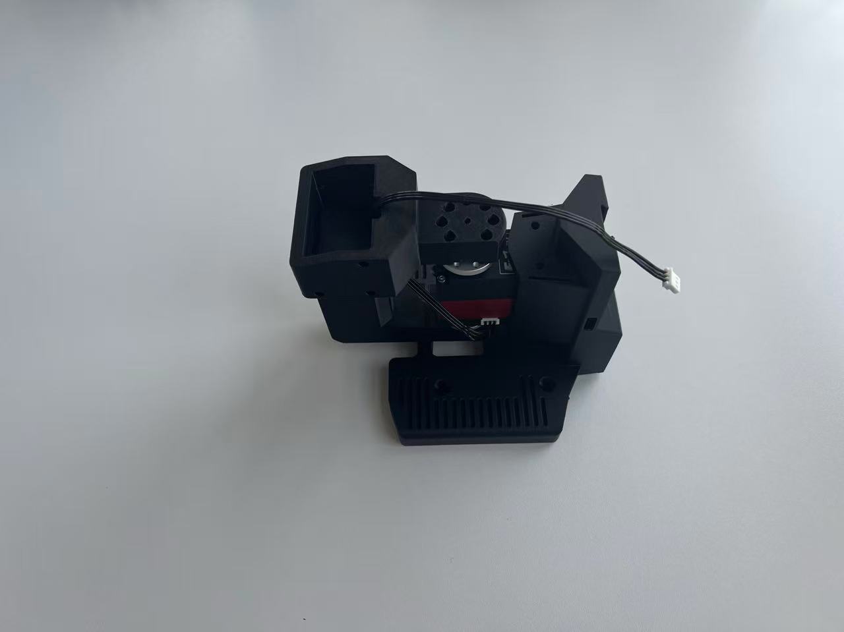
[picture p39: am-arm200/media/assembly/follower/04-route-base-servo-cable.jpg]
Route the base servo cable


Mount the shoulder servos and install the shoulder link.

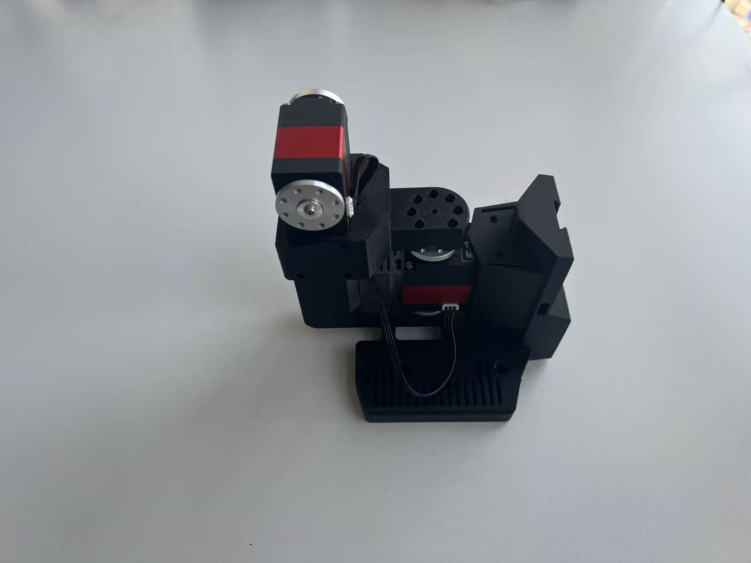
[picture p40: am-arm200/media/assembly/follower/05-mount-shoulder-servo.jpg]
Mount the shoulder servo


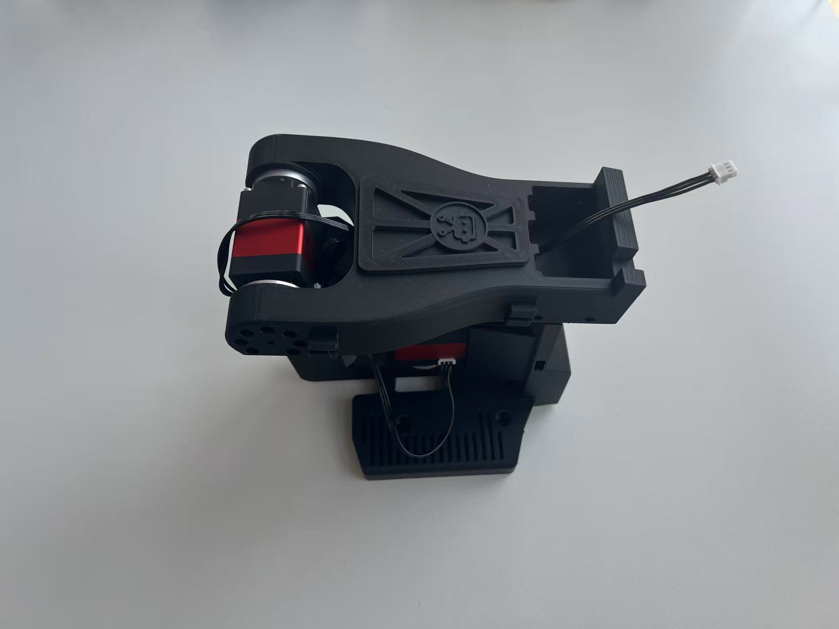
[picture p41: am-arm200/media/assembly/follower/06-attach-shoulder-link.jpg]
Attach the shoulder link


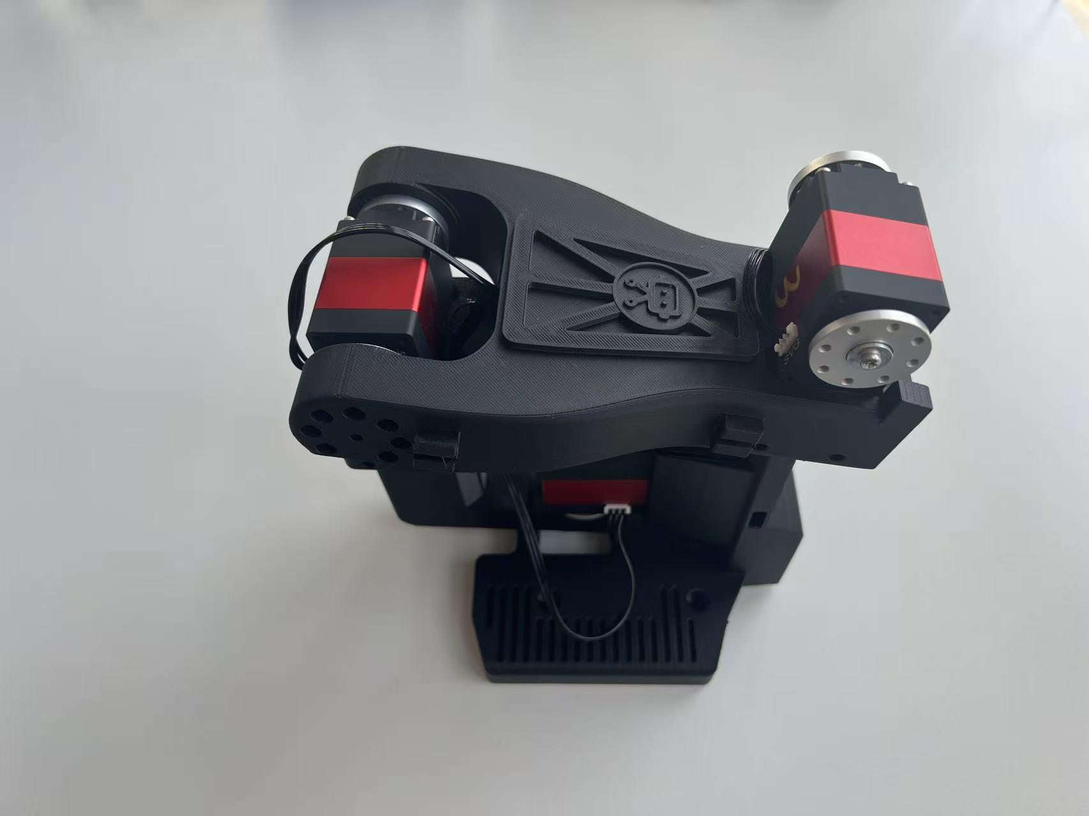
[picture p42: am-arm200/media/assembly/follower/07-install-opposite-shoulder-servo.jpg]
Install the opposite shoulder servo


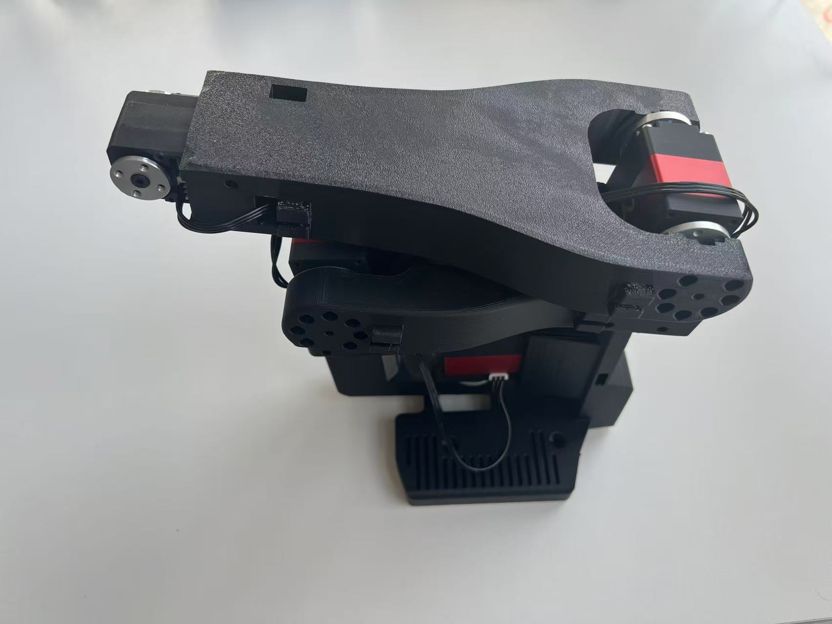
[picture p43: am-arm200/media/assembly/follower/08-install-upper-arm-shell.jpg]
Install the upper arm shell


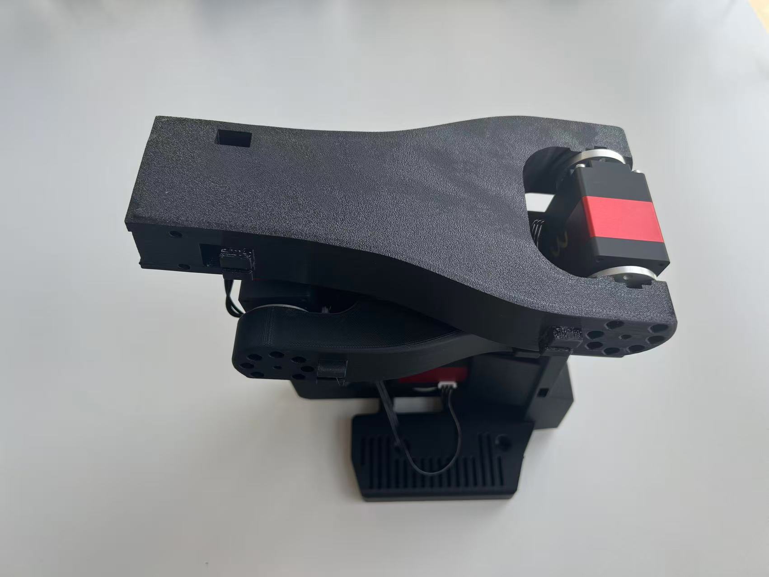
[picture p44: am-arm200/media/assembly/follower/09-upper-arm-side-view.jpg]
Upper arm side view


### 3. Assemble the elbow joint

Install the bearing and spacer, then assemble the elbow servo and printed housing.

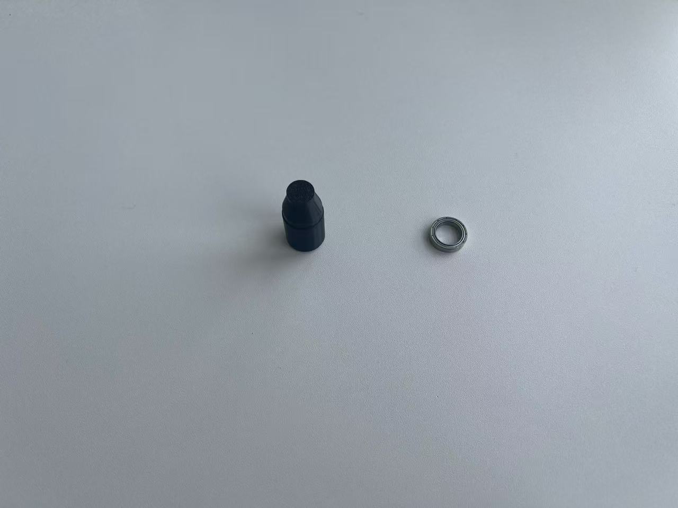
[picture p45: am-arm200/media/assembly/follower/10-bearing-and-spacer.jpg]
Bearing and spacer

Install the pin and bearing. Alternatively, use the no-bearing version: `OB_F_J5_Pin_No_Bearing.stl`.

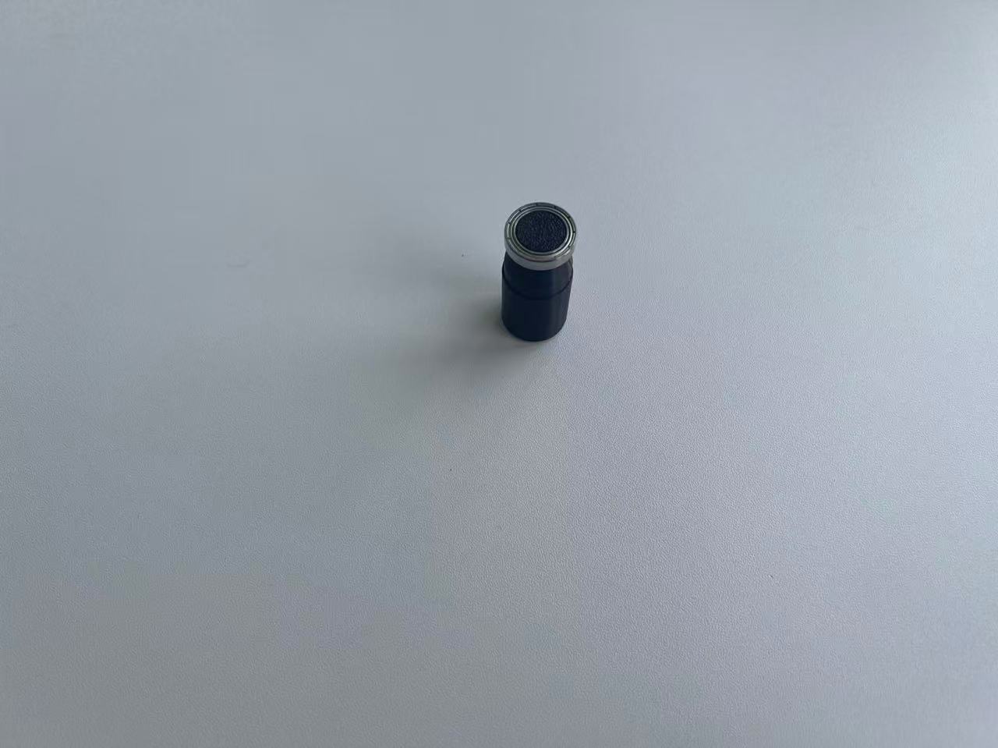
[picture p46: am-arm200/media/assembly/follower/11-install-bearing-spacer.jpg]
Install the bearing spacer


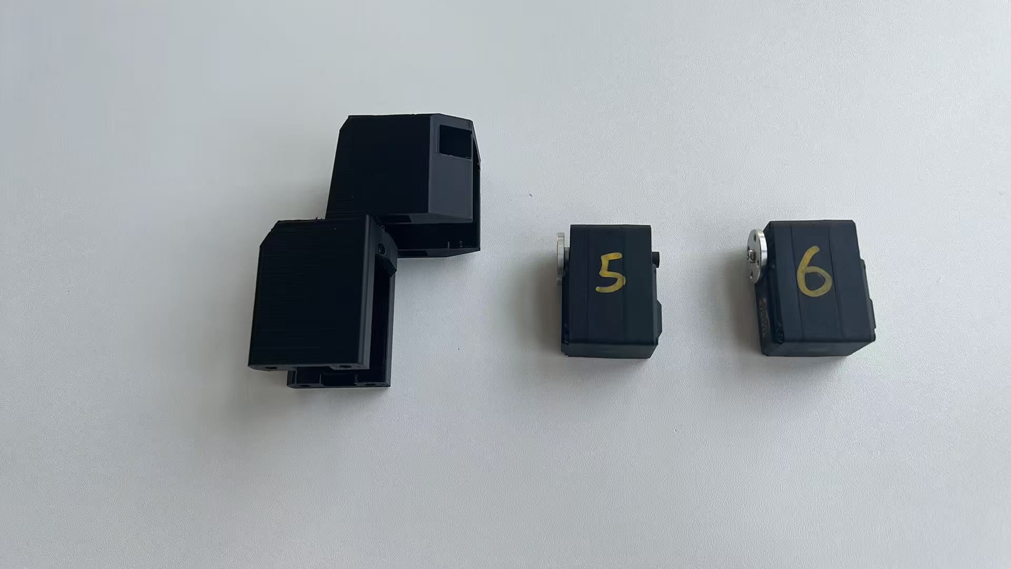
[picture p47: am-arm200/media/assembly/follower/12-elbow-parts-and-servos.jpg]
Elbow parts and servos


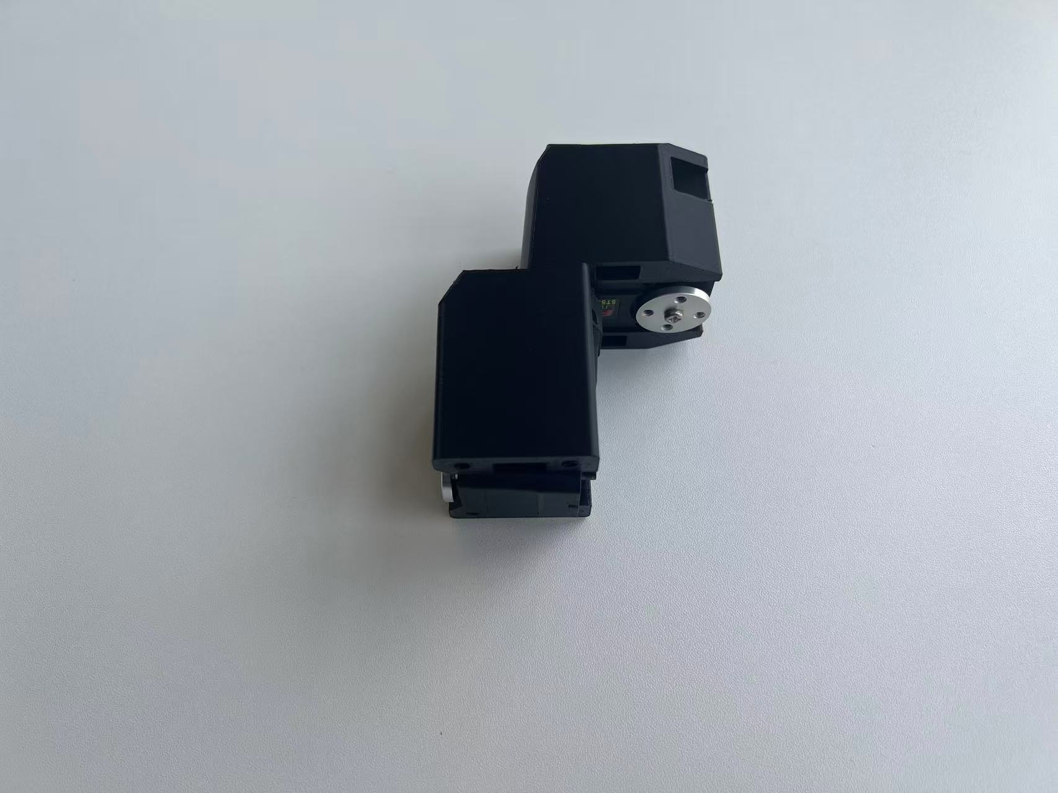
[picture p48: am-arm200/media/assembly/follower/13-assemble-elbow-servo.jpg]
Assemble the elbow servo


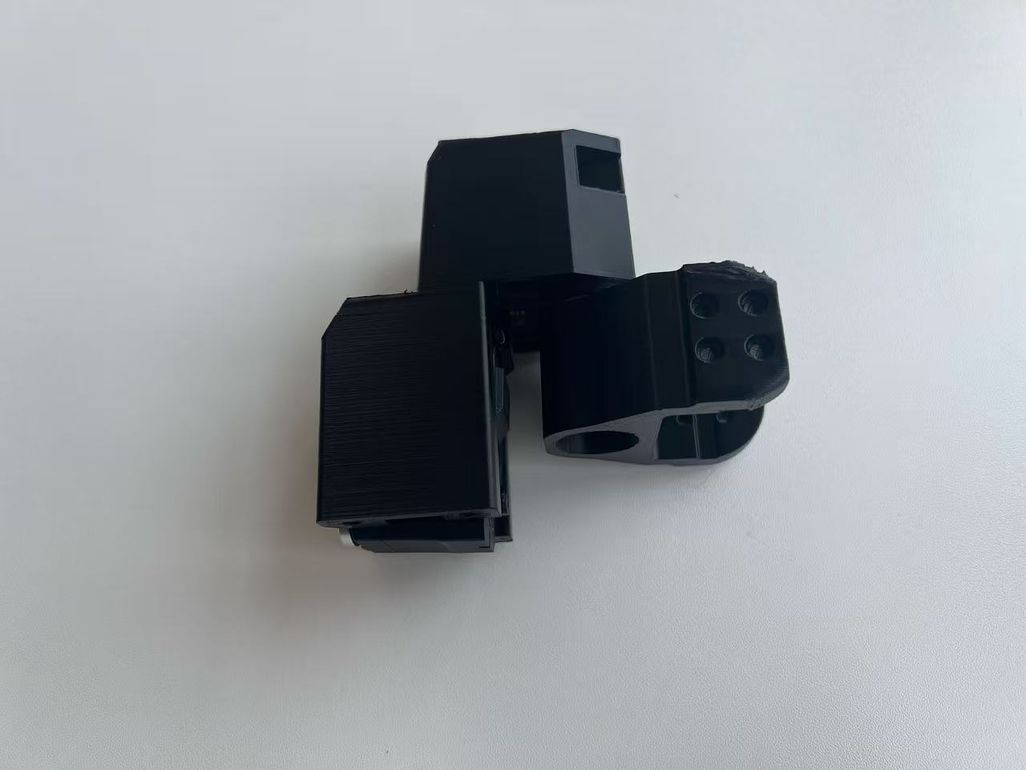
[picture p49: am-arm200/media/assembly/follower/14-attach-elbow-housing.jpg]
Attach the elbow housing


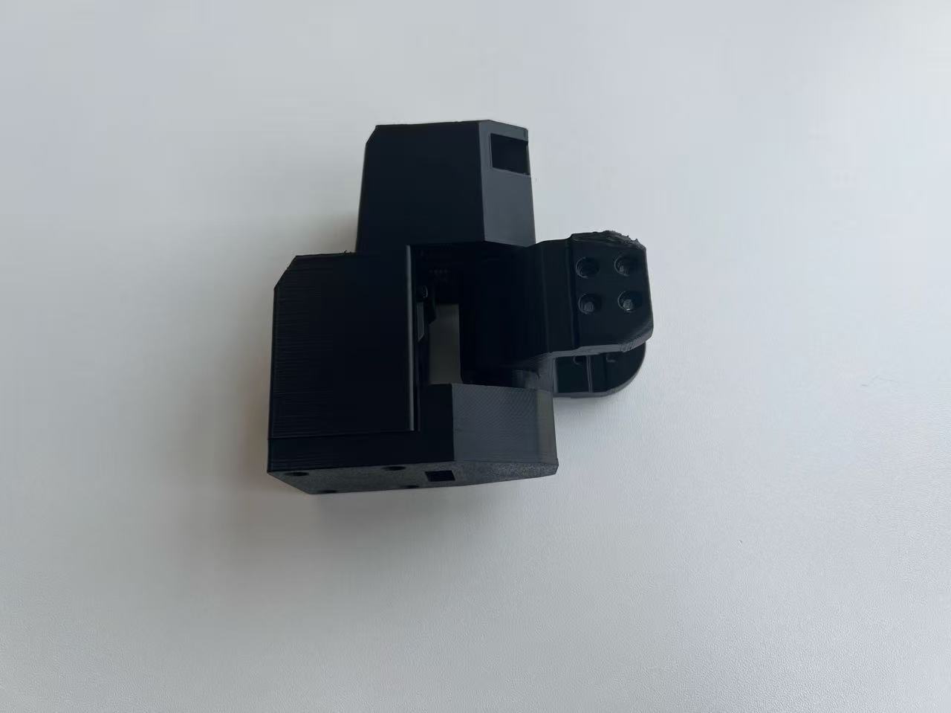
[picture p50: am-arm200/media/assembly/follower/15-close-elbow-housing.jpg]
Close the elbow housing


### 4. Install heat-set inserts

Melt the heat-set inserts into the corresponding holes. Keep the inserts straight and flush with the printed surface.

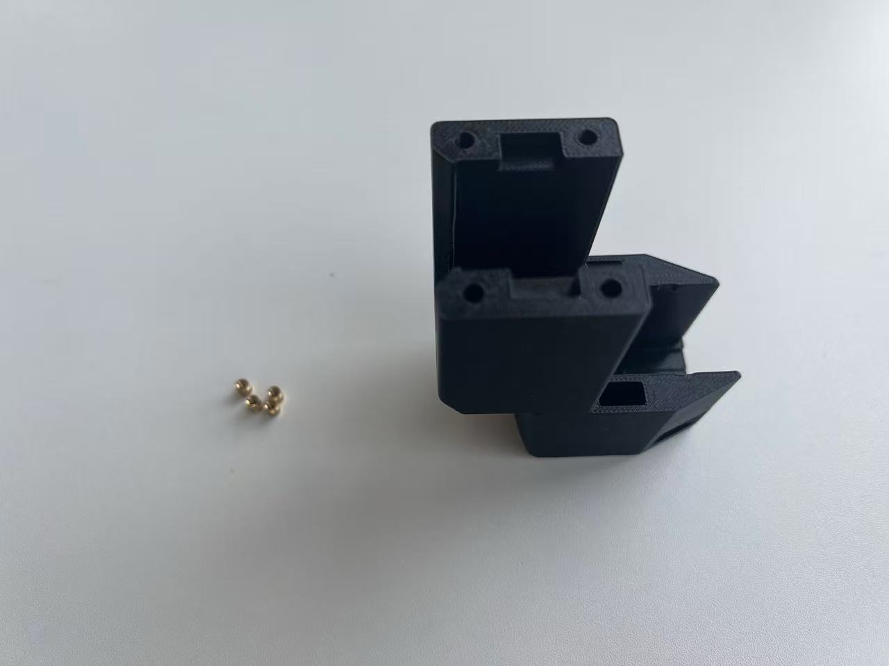
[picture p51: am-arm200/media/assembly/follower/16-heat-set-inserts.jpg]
Heat-set inserts


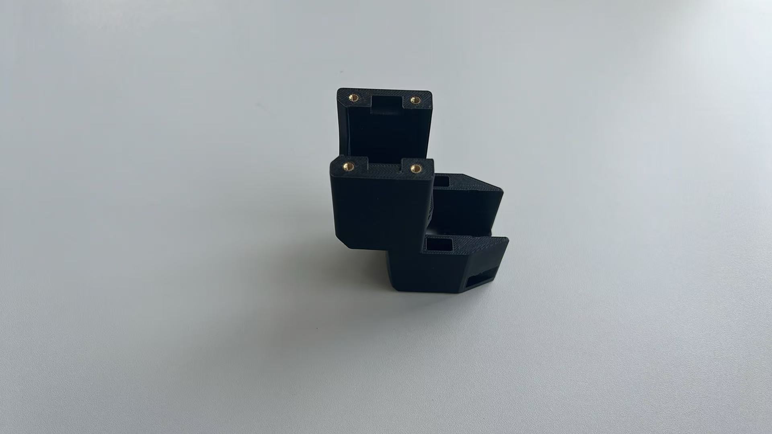
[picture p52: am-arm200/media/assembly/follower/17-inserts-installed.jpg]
Heat-set inserts installed


### 5. Install the wrist and gripper linkage

Route the wrist servo cable before closing the wrist section. Then install the wrist extension and gripper linkage.

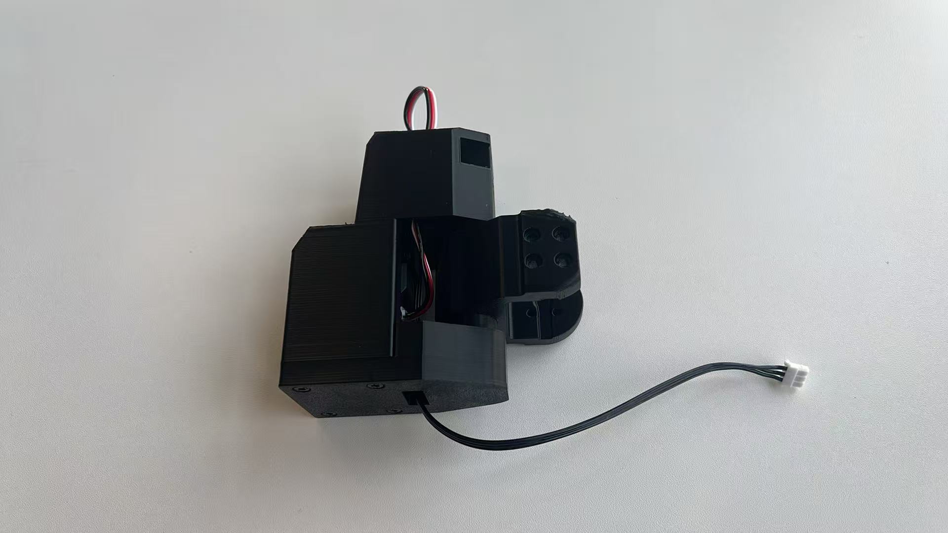
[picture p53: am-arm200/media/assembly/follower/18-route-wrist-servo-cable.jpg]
Route the wrist servo cable


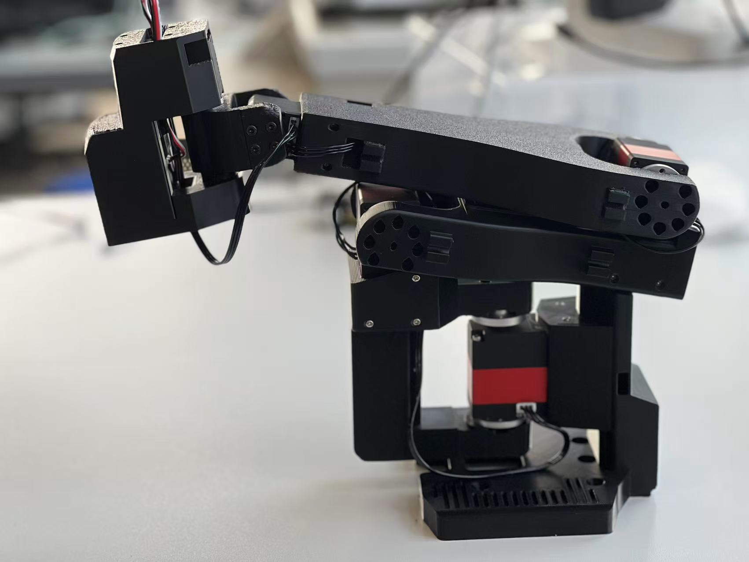
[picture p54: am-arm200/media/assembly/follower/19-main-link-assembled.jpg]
Main link assembled


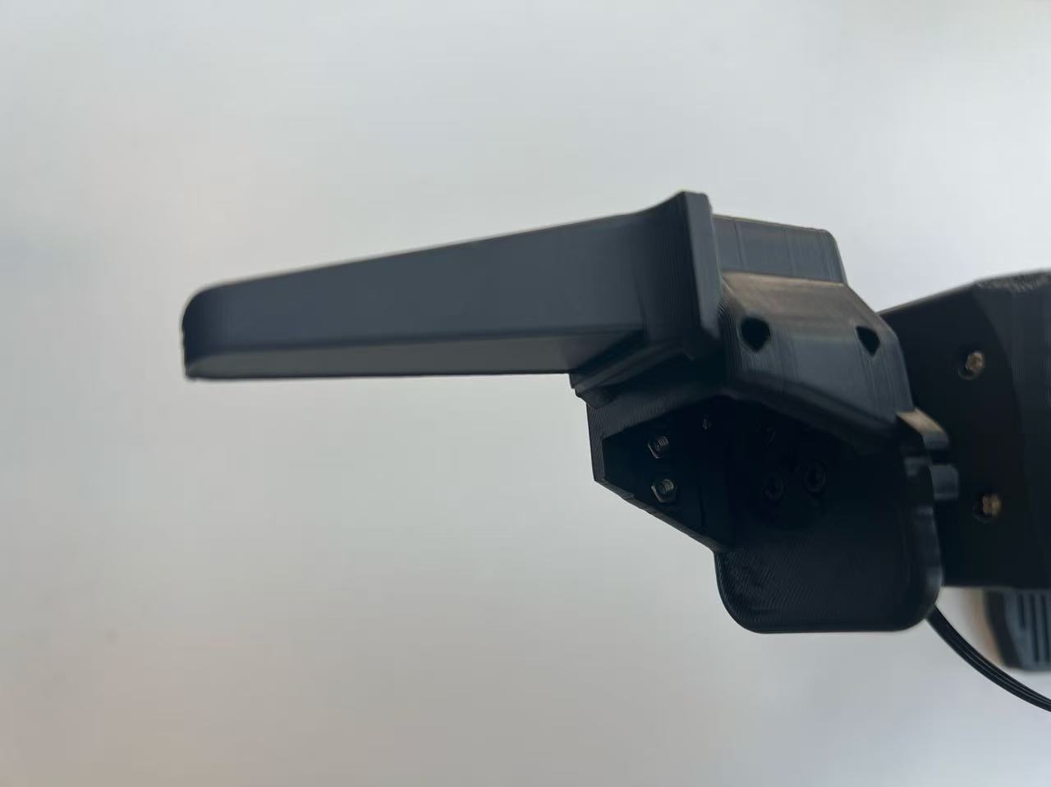
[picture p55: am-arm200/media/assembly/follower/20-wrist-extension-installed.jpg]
Wrist extension installed


Gripper linkage installed

Arm with gripper linkage

### 6. Install the camera mount

Install the camera mount parts at the wrist end.

Camera mount parts

Camera and mount plate
Secure the camera mount with M2x12 screws.
Install the camera mount

Camera mount installed

### 7. Optional gripper friction pads

You can add custom friction pads to the gripper fingers. Use rubber, silicone, or another high-friction material to improve grip.

Optional gripper friction pads

### 8. Install the servo controller

Place the servo controller into the printed cover, then slide the cover into the slot on the base.

Controller board and cover

Controller board installed

### 9. Final check

The follower arm assembly is complete. Check that each joint can rotate through its expected range without cable tension or mechanical interference.

Follower arm complete

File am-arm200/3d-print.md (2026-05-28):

# 3D Printing Guide

All printable files for AM-ARM200 are provided in the `stl` directory. The parts are designed for common FDM printing and can be printed with PLA, PETG, or ABS.

## Recommended Printer

We recommend using a Bambu Lab P2S or a higher-end printer. Other well-tuned FDM printers can also be used, but the printed parts must be dimensionally accurate and mechanically strong enough for servo mounting and load-bearing joints.

## Material

Recommended materials:

- PLA: easy to print and suitable for general use.
- PETG: better toughness and heat resistance than PLA.
- ABS: suitable for higher temperature environments, but requires better chamber temperature control.

## Print Settings

| Part group | Walls | Infill |
|---|---:|---:|
| Follower arm parts | 4-6 walls | 15%-20% |
| Leader arm parts | 2 walls | 15%-20% |

For the follower arm, 4 walls are barely sufficient; 6 walls are strongly recommended.

Use normal layer heights and print speeds recommended by your slicer for the selected material. Make sure all screw holes and heat-set insert holes remain clean and dimensionally accurate.

## Print Orientation

Most parts can be printed in the default orientation shown in the STL files.

Default print orientation for AM-ARM200 parts

For the shoulder and elbow parts, horizontal printing provides better layer direction for strength, but the large contact area may lead to heat-related deformation, especially with materials that require higher bed or chamber temperatures.

Horizontal print orientation for shoulder and elbow parts

If the shoulder or elbow parts warp during horizontal printing, print them vertically instead. Vertical orientation can significantly improve print success rate by reducing the heated footprint on the build plate, but it may reduce strength in some load directions because the layer lines are oriented differently. Use vertical printing as a practical fallback when horizontal printing is unstable.

Vertical print orientation for shoulder and elbow parts

After printing, remove supports carefully and check that all mating surfaces, servo pockets, and screw holes are clean before assembly.

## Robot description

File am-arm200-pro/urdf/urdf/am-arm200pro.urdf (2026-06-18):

<?xml version="1.0" encoding="utf-8"?>
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
<robot name="am-arm200pro">
  <link name="left_Base">
    <inertial>
      <origin xyz="4.0617631907186E-07 0.0110959078409039 0.0236098218621581" rpy="0 0 0" />
      <mass value="0.337097990349248" />
      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
    </inertial>
    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
  </link>
  <link name="left_Rotation_Pitch">
    <inertial>
      <origin xyz="0.00386596201421711 -0.0138668105342394 0.0175130444101314" rpy="0 0 0" />
      <mass value="0.0317343546239167" />
      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
    </inertial>
    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
  </link>
  <joint name="left_shoulder_pan" type="revolute">
    <origin xyz="0 0 0.062556" rpy="0 0 0" />
    <parent link="left_Base" />
    <child link="left_Rotation_Pitch" />
    <axis xyz="0 0 -1" />
    <limit lower="-3.14" upper="3.14" effort="0" velocity="0" />
  </joint>
  <link name="left_Upper_Arm">
    <inertial>
      <origin xyz="-0.00503066993187069 0.0711598496257564 0.0014399982311204" rpy="0 0 0" />
      <mass value="0.26488994104406" />
      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
    </inertial>
    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
  </link>
  <joint name="left_shoulder_lift" type="revolute">
    <origin xyz="0 -0.029035 0.058223" rpy="0 1.5708 0" />
    <parent link="left_Rotation_Pitch" />
    <child link="left_Upper_Arm" />
    <axis xyz="0 0 -1" />
    <limit lower="-3.14" upper="3.14" effort="0" velocity="0" />
  </joint>
  <link name="left_Lower_Arm">
    <inertial>
      <origin xyz="0.00411591741430284 -0.0804551152818728 -0.00101438996817399" rpy="0 0 0" />
      <mass value="0.270278659255739" />
      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
    </inertial>
    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
  </link>
  <joint name="left_elbow_flex" type="revolute">
    <origin xyz="-0.041170749065642 0.128514358904429 0" rpy="0 0 0" />
    <parent link="left_Upper_Arm" />
    <child link="left_Lower_Arm" />
    <axis xyz="0 0 -1" />
    <limit lower="-3.14" upper="3.14" effort="0" velocity="0" />
  </joint>
  <link name="left_Wrist_Pitch_Roll">
    <inertial>
      <origin xyz="-0.000731389938048943 -0.0147937425780408 -0.000718021549161701" rpy="0 0 0" />
      <mass value="0.0304496388844339" />
      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
    </inertial>
    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
  </link>
  <joint name="left_wrist_flex" type="revolute">
    <origin xyz="0.00320470342874501 -0.198428485161884 0" rpy="0 0 0" />
    <parent link="left_Lower_Arm" />
    <child link="left_Wrist_Pitch_Roll" />
    <axis xyz="0 0 1" />
    <limit lower="-3.14" upper="3.14" effort="0" velocity="0" />
  </joint>
  <link name="left_wrist_yaw">
    <inertial>
      <origin xyz="-0.000117813013694405 0.0274410929028983 0.00965024408451137" rpy="0 0 0" />
      <mass value="0.105279930567343" />
      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
    </inertial>
    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
  </link>
  <joint name="left_wrist_yaw_joint" type="revolute">
    <origin xyz="-0.000915704840558335 -0.0281295188165527 -0.000966380385420608" rpy="3.14159257760848 1.5707963267949 0" />
    <parent link="left_Wrist_Pitch_Roll" />
    <child link="left_wrist_yaw" />
    <axis xyz="0 0 -1" />
    <limit lower="-3.14" upper="3.14" effort="0" velocity="0" />
  </joint>
  <link name="left_Fixed_Jaw">
    <inertial>
      <origin xyz="-0.009788697448233 -0.00779183152484197 0.024772169015474" rpy="0 0 0" />
      <mass value="0.0820209259289823" />
      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
    </inertial>
    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
  </link>
  <joint name="left_wrist_roll" type="revolute">
    <origin xyz="0 0.0609927440831215 -0.0242385261486938" rpy="-1.57079640339869 0 0" />
    <parent link="left_wrist_yaw" />
    <child link="left_Fixed_Jaw" />
    <axis xyz="0 0 1" />
    <limit lower="-3.14" upper="3.14" effort="0" velocity="0" />
  </joint>
  <link name="left_Moving_Jaw">
    <inertial>
      <origin xyz="-0.00191495762777895 -0.0312333699899828 0.00285164949308649" rpy="0 0 0" />
      <mass value="0.0288040630212379" />
      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
    </inertial>
    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
  </link>
  <joint name="left_gripper" type="revolute">
    <origin xyz="0.02021444438295 0.0033063194616967 0.021614179864005" rpy="-1.5707963267949 0 3.14159265358979" />
    <parent link="left_Fixed_Jaw" />
    <child link="left_Moving_Jaw" />
    <axis xyz="0 0 1" />
    <limit lower="-3.14" upper="3.14" effort="0" velocity="0" />
  </joint>
  <link name="left_camera">
    <inertial>
      <origin xyz="-0.00363152315829868 0.157740718172186 -0.105680865715653" rpy="0 0 0" />
      <mass value="1.15055846064821" />
      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
    </inertial>
    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
  </link>
  <joint name="left_camera_joint8" type="fixed">
    <origin xyz="0.00251113132165192 -0.071341148343549 -0.00430701398654823" rpy="-0.436362675423314 0 0" />
    <parent link="left_Fixed_Jaw" />
    <child link="left_camera" />
    <axis xyz="0 0.906294954903738 0.422645779247862" />
  </joint>
</robot>

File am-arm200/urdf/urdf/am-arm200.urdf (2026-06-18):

<?xml version="1.0" encoding="utf-8"?>
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
<robot name="am-arm200">
  <link name="left_Base">
    <inertial>
      <origin xyz="-0.000275843336106138 0.0314658115512664 0.0335723553552918" rpy="0 0 0" />
      <mass value="0.319875297446951" />
      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
    </inertial>
    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
  </link>
  <link name="left_Rotation_Pitch">
    <inertial>
      <origin xyz="-0.000892708218042932 -0.0415757409297951 0.0409346003929002" rpy="0 0 0" />
      <mass value="0.170357879655966" />
      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
    </inertial>
    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
  </link>
  <joint name="left_shoulder_pan" type="revolute">
    <origin xyz="0 0 0.039671" rpy="0 0 0" />
    <parent link="left_Base" />
    <child link="left_Rotation_Pitch" />
    <axis xyz="0 0 -1" />
    <limit lower="-3.14" upper="3.14" effort="0" velocity="0" />
  </joint>
  <link name="left_Upper_Arm">
    <inertial>
      <origin xyz="-0.00498717382802011 0.0711768758039328 2.8269043966363E-05" rpy="0 0 0" />
      <mass value="0.263860498133606" />
      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
    </inertial>
    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
  </link>
  <joint name="left_shoulder_lift" type="revolute">
    <origin xyz="0 -0.057994 0.10856" rpy="0 1.5708 0" />
    <parent link="left_Rotation_Pitch" />
    <child link="left_Upper_Arm" />
    <axis xyz="0 0 -1" />
    <limit lower="-3.14" upper="3.14" effort="0" velocity="0" />
  </joint>
  <link name="left_Lower_Arm">
    <inertial>
      <origin xyz="0.00407284254875812 -0.0804991124148977 -0.00296436542896175" rpy="0 0 0" />
      <mass value="0.270063821451467" />
      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
    </inertial>
    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
  </link>
  <joint name="left_elbow_flex" type="revolute">
    <origin xyz="-0.041124 0.12849 0" rpy="0 0 0" />
    <parent link="left_Upper_Arm" />
    <child link="left_Lower_Arm" />
    <axis xyz="0 0 -1" />
    <limit lower="-3.14" upper="3.14" effort="0" velocity="0" />
  </joint>
  <link name="left_Wrist_Pitch_Roll">
    <inertial>
      <origin xyz="-0.000731389938051136 -0.0147937470601834 -0.00272648444717316" rpy="0 0 0" />
      <mass value="0.0304496388845638" />
      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
    </inertial>
    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
  </link>
  <joint name="left_wrist_flex" type="revolute">
    <origin xyz="0.0031575 -0.19841 0" rpy="0 0 0" />
    <parent link="left_Lower_Arm" />
    <child link="left_Wrist_Pitch_Roll" />
    <axis xyz="0 0 1" />
    <limit lower="-3.14" upper="3.14" effort="0" velocity="0" />
  </joint>
  <link name="left_wrist_yaw">
    <inertial>
      <origin xyz="0.000180900832202343 0.0313677255592147 0.00893609906516371" rpy="0 0 0" />
      <mass value="0.114211005073855" />
      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
    </inertial>
    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
  </link>
  <joint name="left_wrist_yaw_joint" type="revolute">
    <origin xyz="0.0012953 -0.02813 -0.0038124" rpy="3.1416 1.5708 0" />
    <parent link="left_Wrist_Pitch_Roll" />
    <child link="left_wrist_yaw" />
    <axis xyz="0 0 -1" />
    <limit lower="-3.14" upper="3.14" effort="0" velocity="0" />
  </joint>
  <link name="left_Fixed_Jaw">
    <inertial>
      <origin xyz="-0.0120468759752292 -0.00928566647448964 0.0250465628307969" rpy="0 0 0" />
      <mass value="0.0743538332299295" />
      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
    </inertial>
    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
  </link>
  <joint name="left_wrist_roll" type="revolute">
    <origin xyz="0 0.060993 -0.022027" rpy="-1.5708 0 0" />
    <parent link="left_wrist_yaw" />
    <child link="left_Fixed_Jaw" />
    <axis xyz="0 0 1" />
    <limit lower="-3.14" upper="3.14" effort="0" velocity="0" />
  </joint>
  <link name="left_Moving_Jaw">
    <inertial>
      <origin xyz="-0.0239309041991747 -0.0212490799756402 0.00157431951783818" rpy="0 0 0" />
      <mass value="0.0281637846719423" />
      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
    </inertial>
    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
  </link>
  <joint name="left_gripper" type="revolute">
    <origin xyz="0.020214 0.0020289 0.021614" rpy="-1.5708 0 3.1416" />
    <parent link="left_Fixed_Jaw" />
    <child link="left_Moving_Jaw" />
    <axis xyz="0 0 1" />
    <limit lower="-3.14" upper="3.14" effort="0" velocity="0" />
  </joint>
  <link name="left_camera">
    <inertial>
      <origin xyz="-0.00381113120491425 0.169561472261356 -0.115134376786152" rpy="0 0 0" />
      <mass value="1.27133656756438" />
      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
    </inertial>
    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
  </link>
  <joint name="left_camera_joint8" type="fixed">
    <origin xyz="0.0018122 -0.07041 -0.0052089" rpy="-0.42318 0 0" />
    <parent link="left_Fixed_Jaw" />
    <child link="left_camera" />
    <axis xyz="0 0 0" />
  </joint>
</robot>

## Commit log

2026-05-28 the first commit
    [OB_F_Camera.stl, OB_F_Camera.stp, OB_F_J3_Shoulder.stl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]
2026-05-30 docs: update README
    [OB_F_J56_Bottom_0501.stp, OB_F_J7_Gripper_0526.stp, OB_F_J7_Jaw_0525.stp]
2026-05-30 docs: update bom
2026-06-18 feat(urdf): add AM-ARM200 URDF model
    [am-arm200.urdf, am-arm200pro.urdf, left_Base.STL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]
